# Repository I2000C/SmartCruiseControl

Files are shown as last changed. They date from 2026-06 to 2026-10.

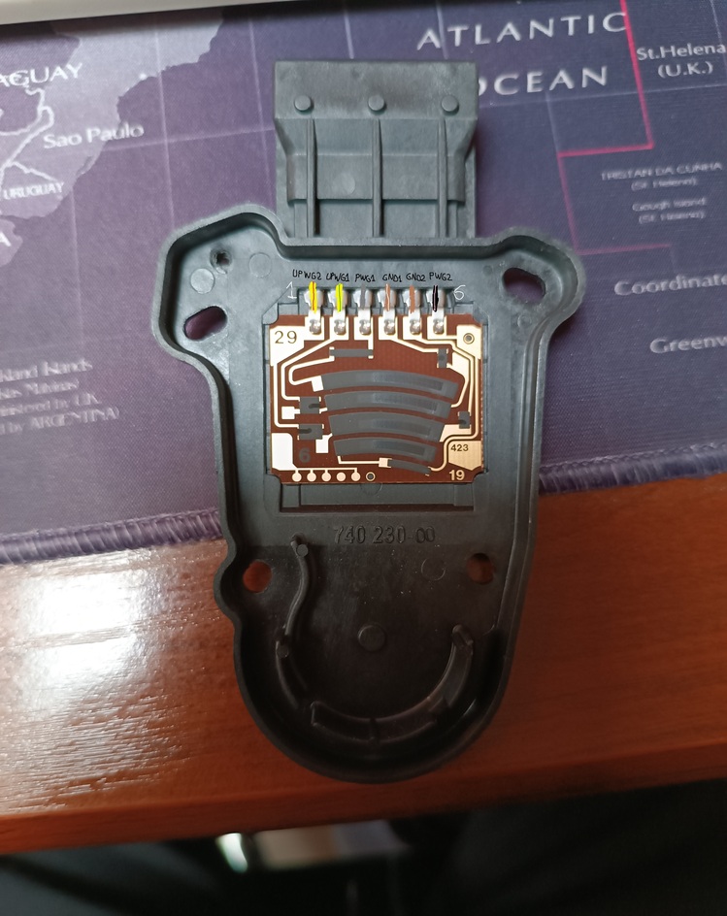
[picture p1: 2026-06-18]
doc/throttle/Throttle potentiometer pinout.jpg

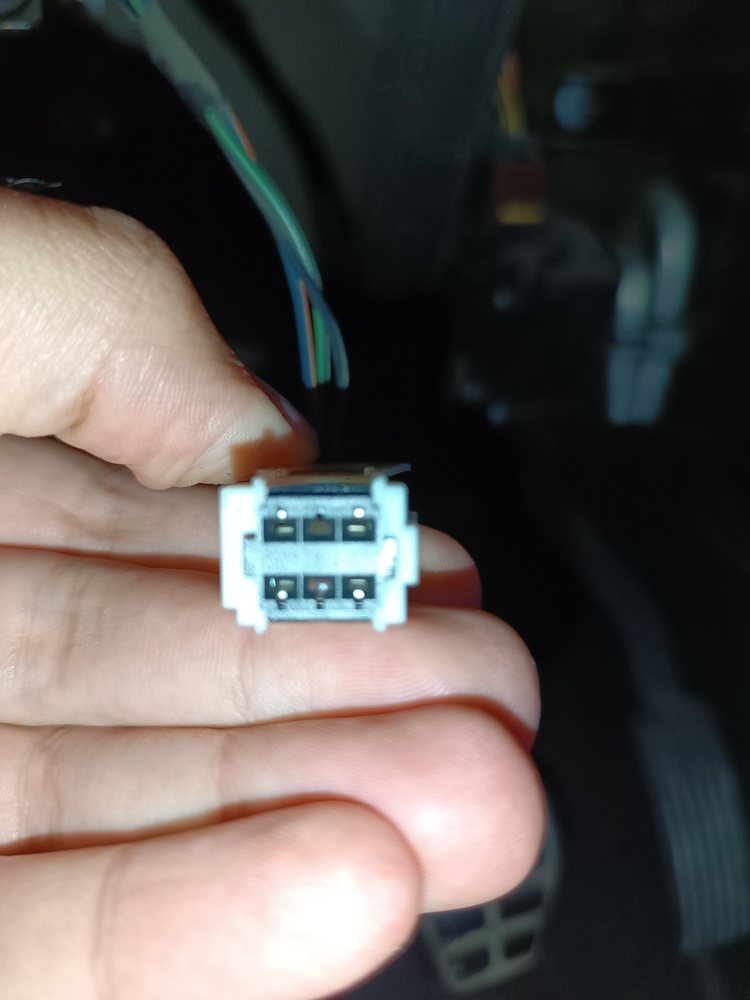
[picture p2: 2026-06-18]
doc/brake_clutch/brake switch connector 2.jpg

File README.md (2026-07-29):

# SmartCruiseControl

SmartCruiseControl is an embedded ESP32 project that implements cruise control using CAN Bus data, with vehicle state monitoring and ELM327 command emulation for the **Smart forfour 454** car

## Description

The software runs on an ESP32 using the Arduino framework and focuses on:

- Reading CAN Bus frames from a Smart vehicle.
- Estimating speed, RPM, distance, fuel level, and other critical vehicle parameters.
- Cruise control with PID, button-based enable/disable, and throttle override handling.
- Basic ELM327 emulation for OBD-II `01xx` and `22xx` command responses.
- Cruise control status indication using an LED.

## Key features

- CAN Bus listen-only mode (`TWAI_MODE_LISTEN_ONLY`) at 500 kbps.
- Support for reading the following key CAN IDs:
  - `0x09E` - total distance
  - `0x200` - speed
  - `0x208` - brake intensity and extra speed data
  - `0x210` - accelerator pedal position
  - `0x308` - engine RPM
  - `0x408` - fuel level
  - `0x416` - battery voltage
  - `0x423` - door status
  - `0x608` - refrigerant temperature and fuel rate
- Cruise control state machine with:
  - `STATE_OFF`
  - `STATE_ACTIVE`
  - `STATE_OVERRIDE`
- ELM327 interface over `Serial` with basic `AT`, `01`, and `22` command handling.

## Project structure

- `platformio.ini` - PlatformIO configuration for ESP32.
- `src/main.cpp` - main entry point and FreeRTOS task setup.
- `include/` - constants, state definitions, and shared headers.
- `lib/` - modular libraries:
  - `can/` - CAN bus reading and decoding.
  - `cruise_control/` - cruise control logic.
  - `elm327/` - ELM327 emulation and OBD response handling.
  - `fuel_range_estimator/` - fuel range estimation.
  - `indicator_led/` - PWM LED status indicator.
  - `pid_controller/` - generic PID controller.
  - `speed_estimator/` - speed estimation from CAN frames.
  - `throttle/` - throttle output and override management.
  - `buttons/` - analog button reading and cruise control button detection.
- `doc/` - CAN Bus reverse engineering documentation.
- `test/` - PlatformIO testing notes and setup.

## Requirements

See `requirements.md` file for required software and hardware

## How to build

See `how-to-build.md` file to build software and hardware

## Usage

- The system starts by creating FreeRTOS tasks for CAN reception, CAN processing, and ELM327 emulation.
- The indicator LED shows cruise control status:
  - off = cruise control disabled
  - full brightness = cruise control active
  - fading = throttle override active
- Cruise control buttons support `SET`, `RESUME`, and `CANCEL`.
- Pressing the accelerator while cruise control is active transitions the system to `STATE_OVERRIDE`.

## Notes

- The project is designed for the Smart Forfour 454 (2006) model, as described at the beginning of `doc/CAN bus reverse engineering.md`.
- With the necessary modifications, it could be adapted to other vehicles that use CAN Bus, electronic throttle, and physical brake/clutch switches.
- The implementation is based on CAN data documented in `doc/CAN bus reverse engineering.md`.
- The ESP32 pinout reference image is available at `doc/ESP32 pinout.png` and is used under Creative Commons BY-NC-ND via www.mischianti.org.

## Inspirations

This project was inspired by:

- [esp32_cruise_control](https://github.com/successdt/esp32_cruise_control)
- [autocruise](https://github.com/SantiagoDelEstero/autocruise)
- [esp32-elm327-cruise-control](https://github.com/ipepe-oss/esp32-elm327-cruise-control)

## License

See the `LICENSE` file for the project license terms.

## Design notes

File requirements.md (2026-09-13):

# Requirements

## Software

- VSCode (https://code.visualstudio.com/)
- PlatformIO extension installed on VSCode (https://platformio.org/install/ide?install=vscode).

## Hardware

- Wires
- Soldering iron (and related soldering stuff)
- A small switch (to safely disconnect power supply if something unexpected happens)
- Male USB to wires
- Female USB to wires
- SN65HVD230
- HK19F-DC 5v-SHG (other DPDT relays may work)
- IRLZ44N x1 (other MOSFETs may work)
- 1N4003 x1 (other flyback diodes may work)
- 2N3904 x4 (other NPN transistors may work)
- Capacitors and resistors. See BOM (Bill of Materials): [BOM](https://html-preview.github.io/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)
- ESP32 devkit v1 board

esp32 board

- Male OBDII connector to wires, including at least **GND**, **CAN low** and **CAN high**

obdII connector to wires

- Throttle connector (reference: XG7061C-1.5-11/21 1473284-1)

XG7061C automotive 6-hole connector

- JST-XH 2.54mm connector kit

JST-XH connector kit

- Steering wheel control button 7 key

steering wheel control button 7 key

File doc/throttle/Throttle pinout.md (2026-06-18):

# Throttle pinouts

## Pinouts
- **UPWG2** (yellow/red wire) = 2.38V (~= 2.5V)
- **UPWG1** (yellow/green wire) = 5V
- **PWG1** (gray wire) = APPS1
- **GND1** (brown/pink wire) = GND
- **GND2** (brown wire) = GND
- **PWG2** (black/pink wire) = APPS2

## Voltage range (measured with multimeter)
- **APPS1**: 0.9772V (0%) --> 3.174V (100%)
- **APPS2**: 0.4588V (0%) --> 1.4850V (100%)

## Relation between APPS 1 and APPS2
APPS1 / APPS2 ~= 2.13

NOTE: APPS means "Accelerator Pedal Position Sensor"

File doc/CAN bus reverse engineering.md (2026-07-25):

# Smart Forfour 454 (2006) CAN Bus Reverse Engineering (1.5 CDI Diesel)

This document describes observed CAN bus frames from a **Smart Forfour 454 (2006, 1.5 CDI diesel)**.  
Values are based on real-world sniffing and are partially reverse engineered.

It has been observed that some signals are similar between this vehicle and the **Smart Fortwo 451**, as documented in the following project:
https://hackaday.io/project/19931-smart-fortwo-can-bus-reverse-engineering

---

## 0x002 — Length: 2 bytes
- Byte 0: Oscillates between 0 and 1
- Byte 1: Counter from 0 to 0xFE (254)

---

## 0x038 — Length: 5 bytes
- Bytes 0–4: Always `0xFF`

---

## 0x09E (+) — Length: 7 bytes
- Bytes 0–2: Always `0xFF`
- Byte 3: Always `0xFE`
- Bytes 4–6: 24-bit value → **total distance traveled (in 0.1 km units)**

---

## 0x0C0 — Length: 5 bytes
- Bytes 0–1: Likely signed 16-bit value (unknown meaning)
- Byte 2: Possibly braking intensity?
- Byte 3: Always `0x07`
- Byte 4: Unknown counter-like value

---

## 0x101 (*) — Length: 8 bytes
Very unusual frame (only sent 5 times)

- Byte 0: 0 → 255 cycle
- Byte 1: 0xC5 → 0
- Byte 2: 0x65 → 0
- Byte 3: 0xEE → 0
- Byte 4: 0x38 → 0
- Byte 5: 0x89 → 0
- Byte 6: 0xB0 → 0
- Byte 7: 0x50 → 0

---

## 0x111 (*) — Length: 8 bytes
Sent only 4 times

- Byte 0: Always 0
- Byte 1: Always 0xAB
- Byte 2: Always 0x17
- Byte 3: Always 0x1A
- Bytes 4–7: Always 0

---

## 0x119 (*) — Length: 8 bytes
Sent only 9 times

- Bytes 0–1: Always 0
- Byte 2: 1 → 0 transition
- Bytes 3–4: Always 0
- Byte 5: Always 0x08
- Byte 6: Increases slowly from 1 to 9
- Byte 7: Varies (0x03 → 0xB8)

---

## 0x130 — Length: 8 bytes
- Byte 0: Oscillates between 0 and 11
- Byte 1: Fast counter (0 → 0xFE)
- Byte 2: Unknown
- Bytes 3–5: Oscillating values
- Byte 6: Usually 0 (rare peak at 0x08)
- Byte 7: Counter-like (0 → 0xFF)

---

## 0x194 (*) — Length: 1 byte
- Byte 0: Always `0xFE`

---

## 0x1A4 (*) — Length: 8 bytes
Constant frame

- Byte 0: 0x05
- Byte 1: 0x03
- Byte 2: 0x20
- Byte 3: 0x02
- Byte 4: 0x0B
- Byte 5: 0xC3
- Bytes 6–7: Always 0

---

## 0x1E1 — Length: 8 bytes
- Byte 0: 0x81 → 0 → stays 0
- Bytes 1–7: Always 0

---

## 0x200 — Length: 8 bytes
- Byte 0:
  - Bit 1: **Handbrake status**
- Byte 1: Counter (0 → 0x7D)
- Bytes 2–3: **Vehicle speed (km/h × 0.05)**
- Bytes 4–5: **Vehicle speed (km/h × 0.05)**
- Bytes 6–7: **Vehicle speed (km/h × 0.05)**

---

## 0x208 (+) — Length: 8 bytes
- Byte 0: Always 0
- Byte 1: 0x30 → 0x20 → stable
- Bytes 2–3: **Brake intensity (max value: 0x4230)**
- Bytes 4–5: **Vehicle speed (km/h × 0.05)**
- Bytes 6–7: **Vehicle speed (km/h × 0.05)**

---

## 0x210 (+) — Length: 8 bytes
- Bytes 0–1: Always 0
- Byte 2: **Accelerator pedal sensor 1 (0 → 0xA1)**
- Byte 3: Transient value, stabilizes at 0x40
- Bytes 4–7: Always 0

---

## 0x212 (+) — Length: 8 bytes
- Byte 0: 0 → 3
- Byte 1: 0 → 0x86 → 0x84
- Bytes 2–3: Always 0
- Bytes 4–5: **Accelerator pedal sensor 2 (0x277C → 0x2A0A)**
- Bytes 6–7: Always 0

---

## 0x270 (*) — Length: 8 bytes
- Bytes 0–1: Counters (0 → 0xFF)
- Bytes 2–7: Always 0xFF

---

## 0x2F1 — Length: 2 bytes
- Byte 0: Unknown
- Byte 1: 0x80 → 0

---

## 0x300 — Length: 8 bytes
- Byte 0: Always 0
- Byte 1: 0x08 → 0x8D
- Byte 2: Always 0x1F
- Byte 3: Always 0xFF
- Byte 4: 0 → 0x80 oscillation
- Byte 5: Always 0
- Bytes 6–7: Unknown 16-bit value

---

## 0x308 (+) — Length: 8 bytes
- Byte 0: 0 or 0x80 (state-dependent)
- Bytes 1–2: **Engine RPM (16-bit)**
- Byte 3: 0x0C → 0x00 decay
- Byte 4: 0x10 → spike → 0
- Byte 5: Unknown (0xFF → 0x82 stabilizing)
- Byte 6: Always 0x20
- Byte 7: Always 0

---

## 0x312 — Length: 8 bytes
All fields unknown (16-bit blocks)

---

## 0x328 — Length: 8 bytes
- Bytes 0–1: Always 0xFF
- Byte 2: Oscillates (0x3B → 0xB8)
- Byte 3: Always 0
- Byte 4: 0xDF → 0xC0 → 0xD0 → 0xC0
- Byte 5: Oscillates (0–0x47)
- Bytes 6–7: Counters (0 → 0xFF)

---

## 0x408 (+) — Length: 8 bytes
- Byte 0: **Fuel tank level (liters)**
- Byte 1: Always 0
- Byte 2: ~110 (0x6E)
- Byte 3: Always 0
- Byte 4: Always 0xFE
- Byte 5: Always 0xC3
- Byte 6: Always 0x4F
- Byte 7: Always 0

---

## 0x40C (+) — Length: 5 bytes
- Byte 0: Always 0xFF
- Byte 1: **Speed (dashboard km/h)**
- Byte 2: Always 0x80
- Byte 3: Always 0
- Byte 4: Always 0x40

---

## 0x412 — Length: 8 bytes
- Byte 0: Always 1
- Byte 1: **Speed (dashboard km/h + slightly offset)**
- Byte 2: Always 2
- Byte 3: 0xA0
- Byte 4: Slowly increasing unknown value
- Byte 5: Always 0
- Byte 6: Always 1
- Byte 7: 0xDF

---

## 0x416 (+) — Length: 8 bytes
- Byte 0: **Battery voltage (in 0.1V units)**
- Bytes 1–7: Always 0

---

## 0x423 (+) — Length: 6 bytes
- Byte 0:
  - Bits 0–1: **Ignition state (LOCK = 0b00 / ACC = 0b01 / ON = 0b11 / START = 0b10)**
  - Bit 2: **Position lights**
  - Bit 3: **Front fog lights**
  - Bit 4: **Rear fog light**
- Byte 1:
  - Bit 0: **Right turn signal**
  - Bit 1: **Left turn signal**
  - Bit 2: **High beam headlights**
  - Bit 3: **Reverse light**
- Byte 2:
  - Bit 0: **Right front door**
  - Bit 1: **Left front door**
  - Bit 3: **Right rear door**
  - Bit 4: **Left rear door**
  - Bit 6: **Trunk door**
- Byte 3:
  - Bit 0: **Fan state**
- Byte 4: Always 0x15
- Byte 5: 0x05–0x06

---

## 0x443 (*) — Length: 6 bytes
- Byte 0: 0 → 2 spike
- Byte 1: 0xFF → 0 → 0x23 cycle
- Bytes 2–5: Always 0

---

## 0x536 (*) — Length: 8 bytes
Constant diagnostic-like frame

- Byte 0: 0xAB
- Byte 1: 0x68
- Byte 2: 0x4C
- Byte 3: 0xB1
- Byte 4: 0x0C
- Byte 5: 0
- Byte 6: 0x02
- Byte 7: 0

---

## 0x608 (+) — Length: 8 bytes
- Byte 0: **Coolant temperature (°C + offset 40)**
- Byte 1: Always 0
- Byte 2: 0x18
- Byte 3: 0x66
- Byte 4: 0xFF
- Bytes 5–6: **Fuel consumption (L/h × 0.01)**
- Byte 7: Always 0

---

## 0x7C0 (*) — Length: 2 bytes
Single transmission frame

- Byte 0: 0x53
- Byte 1: 0xF5

---

## Notes
- Frames marked with `(*)` are rare or burst transmissions.
- Frames marked with `(+)` likely contain key vehicle state signals.
- Several signals are still unknown and require further reverse engineering.

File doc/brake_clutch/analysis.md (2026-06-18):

# Brake and Clutch Switch Analysis (Smart Forfour 454, 2006)

## System Overview

Both the brake and clutch pedals use simple switch assemblies that interface with the ECU through pull-up resistors. The ECU reads these signals as logic levels (approximately 0 V or ~12 V depending on pedal state), rather than clean digital GPIO-style signals.

Both switches behave similarly:

* **ECU input is pulled up internally to ~12 V**
* **Switch closure pulls the signal to GND**

# Brake Switch

## Pinout

The brake switch uses a 4-pin connector with the following wiring:

* Brown wire: **+12 V supply**
* Black wire: **GND**
* Green/black wire: **ECU signal**
* Blue/orange wire: **Brake lights output**

### Internal grouping

The switch contains two independent circuits:

* **Power to brake lights**

  * +12 V ↔ Brake lights
* **ECU sensing circuit**

  * GND ↔ ECU signal

## Physical location and identification

The brake switch is located at the pedal assembly and its connector and wiring can be identified in the following images:

* `brake switch connector.jpg`
* `brake switch connector2.jpg`
* `brake switch connector3.jpg`

These images show the physical connector, pin arrangement, and wiring colors used for identification.

## Electrical behavior

### Brake NOT pressed (idle state)

* GND is connected to ECU pin
* ECU sees approximately **0 V**
* Brake lights circuit is open

### Brake PRESSED

* +12 V is connected to brake lights output
* ECU input is disconnected from GND and pulled up internally
* ECU sees approximately **11–12 V**

Measured behavior:

* Idle: ~0 V at ECU pin
* Active: ~11–12 V at ECU pin

## ECU pull-up resistor estimation

Measurements using an external 100 kΩ resistor allowed estimation of the internal pull-up:

* Without external load: ~11.22 V
* With 100 kΩ load: ~10.98 V

Estimated internal pull-up resistance:

* **≈ 2.2 kΩ**

## Signal conditioning for microcontroller (ESP32)

Since the ECU signal operates at automotive voltage levels (~12 V), direct connection to an ESP32 GPIO is not safe.

### Recommended approach: NPN transistor interface

A simple level-shifting circuit can be used using a **2N3904 NPN transistor**.

**Connections:**

* Base (B): ECU signal via **10 kΩ resistor**
* Collector (C): ESP32 GPIO input (with pull-up enabled)
* Emitter (E): GND

This inverts the signal:

* Brake NOT pressed → GPIO HIGH
* Brake pressed → GPIO LOW

# Clutch Switch

## Pinout

The clutch switch is electrically similar to the brake ECU sensing circuit but simpler:

* Black wire: **GND**
* Red/yellow wire: **ECU signal**

Only two wires are present because this switch does not control any secondary load like brake lights.

## Physical location and identification

The clutch switch is located behind the fuse box and is not directly visible. Access is limited, so the correct wire was identified by probing, testing, and carefully pulling and tracing the harness until the correct signal line was found.

The identified clutch signal wire is shown in:

* `clutch switch wire.jpg`
* `clutch switch wire2.jpg`

## Electrical behavior

### Clutch NOT pressed (idle state)

* ECU signal is pulled up internally
* Measured voltage: **~11.7 V**

### Clutch PRESSED

* Signal is pulled to ground
* Measured voltage: **~0 V**

Measured with external 100 kΩ reference resistor:

* With load: ~11.4 V
* Without load: ~11.7 V

## ECU pull-up resistor estimation

Estimated internal pull-up:

* **≈ 2.6 kΩ**

This is consistent with the brake circuit and indicates a similar ECU input design.

## Signal conditioning for ESP32

The same NPN transistor approach applies:

* Base: ECU signal via 10 kΩ resistor
* Collector: ESP32 GPIO (pull-up enabled)
* Emitter: GND

Logic is inverted:

* Clutch released → HIGH
* Clutch pressed → LOW

# Notes

* Both pedal inputs are **12 V automotive logic signals**, not direct digital inputs.
* Internal ECU pull-ups are relatively low (~2–3 kΩ), indicating relatively strong signal driving capability.
* Using a transistor interface is strongly recommended for reliability and protection of microcontroller inputs.
* Measurement consistency suggests both brake and clutch inputs share a similar ECU input architecture, despite slight differences in pull-up values.

# Circuit visualization

The electrical circuit of the brake pedal switch (the clutch switch is not shown due to its very similar behavior) can be visualized using the Falstad Circuit Simulator:

* Go to: https://www.falstad.com/circuit/circuitjs.html
* Load the file: `brake-pedal-switch-circuit.txt`

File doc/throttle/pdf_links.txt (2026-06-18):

These 2 pdf files have been downloaded from:
https://es.scribd.com/document/216611532/Smart-Forfour-454-Wiring-Diagram
https://es.scribd.com/document/577662516/Smart-FORFOUR-2006-Wiring-Diagram-of-Engine-Electronics-Electronic-Accelerator-Transmission-MEG-With-Clutch-Sheet-2
https://es.scribd.com/document/444638970/Sensor-del-pedal-del-acelerador

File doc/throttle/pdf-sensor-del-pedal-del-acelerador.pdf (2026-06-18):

## Somsir hol pohel hol ecolorehir

### Códi cimocter ol isckliscipki pere roelkzer ume pruo`e7-Somsir ho piskckóm hol ecolorehir

Cimocto ol tordkmel ho cidpri`eckóm @MC om ol cemel E hol ^kciScipo. Ciliquo ume `rkhe ho cicihrkli mofre om le simhe mofre (mofetkvi) y cimocto oste e um pumti ho tide
ho tkorre ehocuehi. Cimocto ume simhe ho ecupumture el tordkmel rigi (pisktkvi) pere roelkzer ume ho les cimoxkimos hol pitomckódotri homtri ho le tide d÷ltkplo hol somsir ho piskckóm hol pohel hol ecolorehir, tel y cidi so duostre om le tre om le Jkfure ?0.5.

Cimocto ol tordkmel ho cidpri`eckóm @MC om ol cemel @ hol ^kciScipo. Cimocto ume
simhe ho ecupumture el tordkmel rigi (pisktkvi) pere roelkzer le itre cimoxkóm el pitomckódotri homtri ho le tide d÷ltkplo hol somsir hol pohel hol ecolorehir r hol pohel hol ecolorehir. Sk bey . Sk bey
tordkmel ho eutidickóm hkspimk`lo, puoho utklkzerso om lufer hol dëtihi ho "`eca-pkmmkmf".

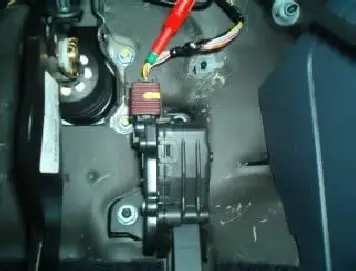
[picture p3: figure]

Jkf. ?0.5
Ogodpli ho jirde ho imhe hol Ogodpli ho jirde ho imhe hol somsir ho piskckóm hol somsir ho piskckóm hol

### pohel hol ecolorehir

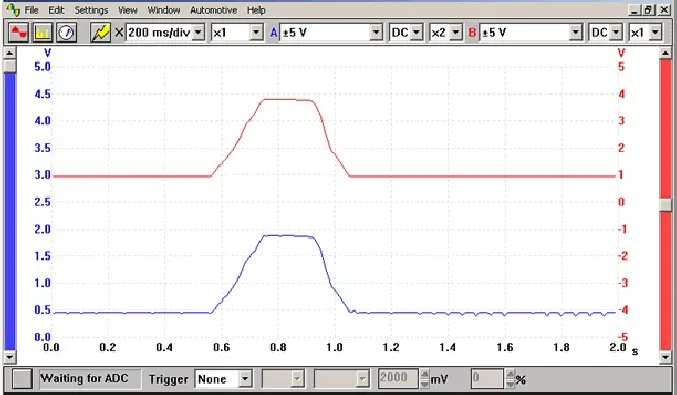
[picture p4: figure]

Mites si`ro le jirde ho imhe ho Mites si`ro le jirde ho imhe ho cimtril hol ecoloreh cimtril hol ecolorehir

### oloctrómkci

Om osto ogodpli, ol somsir ho piskckóm hol pohel hol ecolorehir (E^^) os ho tkpi pitomckódotri. Pock`o his tomskimos ho rojoromck pitomckódotri. Pock`o his tomskimos ho rojoromcke hosho ol dóhuli ho cimtril hol trom ho hosho ol dóhuli ho cimtril hol trom ho pitomcke (^CD), cim his ce`los ho tide ho tkorre pitomcke (^CD), cim his ce`los ho tide ho tkorre y his ce`los ho soõel quo omväem ume his ce`los ho soõel quo omväem ume tomskóm verke`lo ho rofrosi el ^CD om roleckóm cim le piskckóm hol pohel hol ecolorehir. Le tomskóm ho le soõel omvkehe el ^CD puoho verker ho um je`rkcemto e itri, pori pri`e`lodomto mumce sorå suporkir e ? pri`e`lodomto mumce sorå suporkir e ? viltkis. viltkis.

### Kmjirdeckóm tëcmkce - Cimtril hol ecolorehir oloctrómkci

El eudomter ol mkvol hol cimtril oloctrómkci y le cimskfukomto rohucckóm om ol m÷dori ho pkozes docåmkces dóvklos, os kmovkte`lo quo voedis dås olodomtis cimtrilehis dohkemto olodomtis cimtrilehis dohkemto ce`lo.

_m ogodpli ho osti os ol cimtril hol ecolorehir. Le deyir perto ho lis vobäculis je`rkcehis om le ectuelkheh mi utklkzem um ce`lo pere ol ecolorehir, skmi um E^^ om cid`kmeckóm cim um ectuehir ho cimtril hol ecolorehir oloctrómkci (OXC), kmcirpiremhi um ditir ho ecolorehir oloctrómkci y um somsir ho piskckóm hol ecolorehir (X^S).

Ol E^^ suolo sor umi, i dås cid÷mdomto, his pitomckódotris eciplehis el pohel hol ecolorehir. Cuemhi so pkse ol ecolorehir, ume soõel ho tomskóm so omväe el ^CD

cidumkcemhi le piskckóm ectuel hol dksdi y pir li temti le oxkfomcke jäskce hol cimhuctir. Cidi rosultehi ho oste omtrehe, ol ^CD fomore ume selkhe el ectuehir cirrospimhkomto, om osto cesi ol OXC. Cidi so be domckimehi emtorkirdomto, ol E^^ suolo tomor his pitomckódotris. Ëstis so utklkzem cidi pruo`e ho pleusk`klheh y ted`këm pere esofurer um k`klheh y ted`këm pere esofurer um mkvol ho jumckimedkomti e pruo`e ho jellis.

So utklkzem verkis dëtihis pere fomorer le soõel. Le frem deyiräe utklkze le rojoromcke cid÷m ho ? viltkis, quo so odploe om ol skstode ho fostkóm hol ditir. Lis his dëtihis dås cidumos ho fomoreckóm ho soõelos sim lis skfukomtos7

### 5. Ol pitomckódotri 5 fomore ume soõel ho omtro >,3 y 8,2 viltkis (pkste rige om le

jkfure ?0.0) y ol pitomckódotri 0 fomore ume soõel ho omtro >,? y 8,2 viltkis (pkste ezul om le jkfure ?0.0). Cim ume piskckóm hol pohel hol ecolorehir e 8? frehis, ol pitomckódotri 5 puoho odktkr ume soõel ho 0 viltkis y ol pitomckódotri 0 ume s s y ol pitomckódotri 0 ume soõel ho 3 viltkis, e dihi ho ogodpli.

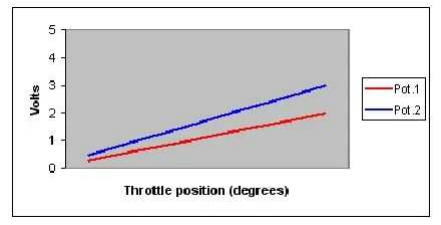
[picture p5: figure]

Jkfure ?0.0

### 0. Ol pitomckódotri 5 fomore ume soõel ho omtro >,3 y 8,2 viltkis (pkste rige om le

jkfure ?0.3) y ol pitomckódotri 0 fomore ume soõel ho omtro 8,2 y >,3 viltkis (pkste ezul om le jkfure ?0.3). Cim ume piskckóm hol pohel hol ecolorehir e > frehis, ol pitomckódotri 5 puoho odktkr ume soõel ho >,? viltkis y ol pitomckódotri 0 ume y ol pitomckódotri 0 ume soõel ho 8,? viltkis.

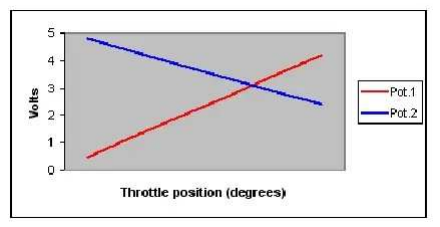
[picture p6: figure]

Jkfure ?0.3

Xres le rocopckóm ho les soõelos ho osto dihi, ol ^CD os cepez ho esofurer quo le kmjirdeckóm os cirrocte1 pir ogodpli, sk ol åmfuli E^^ os ho 8? frehis, ol pitomckódotri 5 odkto 0 viltkis y ol pitomckódotri 0 odkto 3 viltkis. Sk so prihuco elfume hosvkeckóm rospocti e ostis veliros, ol ^CD hotocte um pisk`lo jelli y rofkstre ol cóhkfi ho evoräe cirrospimhkomto. Sk ume pkste ho um pitomckódotri ceo, ol ^CD sorå cepez ho hotocter osti ted`këm y jumckimer om dihi e pruo`e ho jellis i ho odorfomcke, e domuhi olovemhi ol relomtä y lkdktemhi ol jumckimedkomti hol ecolorehir, kludkmemhi ted`këm le luz kmhkcehire ho evoräes (DKL). Ol usi ho lis his pitomckódotri ted`këm pordkto el ^CD cimtriler le volickheh e le quo so pkse ol ecolorehir y so ckorre le piskckóm hol ecolorehir, cimtrilemhi
esä le omtrehe ho cid`ustk`lo.

Jirdes ho imhe emirdelos - rosiluckóm ho Jirdes ho imhe emirdelos - rosiluckóm ho pri`lodes pri`lodes

Sk croo quo puoho be`or um pri`lode cim le soõel, cidpruo`o ol ce`loehi hosho ol ^CD el E^^.

Esof÷roso ho quo ol ^CD tkomo ume elkdomteckóm ehocuehe y ho quo so cimocte e tkorre cuemhi so roqukoro.

Cidpruo`o ol E^^ (hoscimoctehi) cim um ibdädotri.

### Hetis ho pkm

Ogodpli ho hetis ho pkm

Cidpri`ehi om um cidpimomto Sdert Jirjiur 5.5 ho fesilkme 0>>? D[. Bolle
cimoctir ho : pkms

Jkfure ?0.8

^km 54 0,? Z ho tomskóm ho rojoromcke (ederklli/rigi)
^km 04 ?,> Z ho tomskóm ho rojoromcke (ederklli/vorho)
^km 34 tomskóm ho soõel, eprix. 5 Z cim ol ecolorehir correhi y 3,2 Z cim ol ecolorehir e`korti (frks)
^km 84 > Z tide ho tkorre (derróm/`lemci)
^km ?4 > Z tide ho tkorre (derróm)

^km :4 Xomskóm ho soõel, eprix. >,? Z ecolorehir correhi y 5,2 Z ecolorehir e`korti (rise/mofri)

Xihes les ckjres kmhkcehes sim eprixkdehes y i`tomkhes dohkemto "`eca-pkmmkmf" cim ol omcomhkhi ectkvehi y le tide d÷ltkplo cimoctehe.

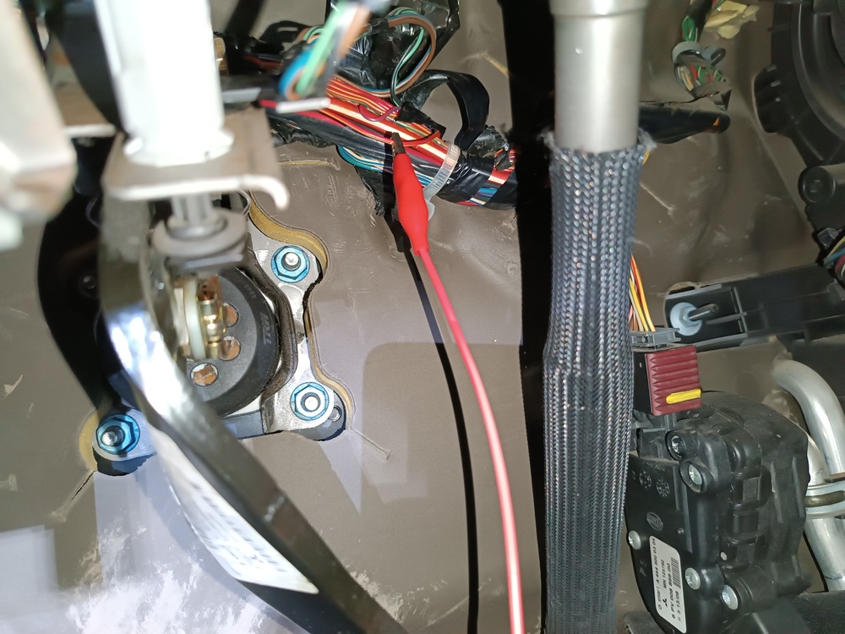
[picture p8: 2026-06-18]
doc/brake_clutch/clutch switch wire.jpg

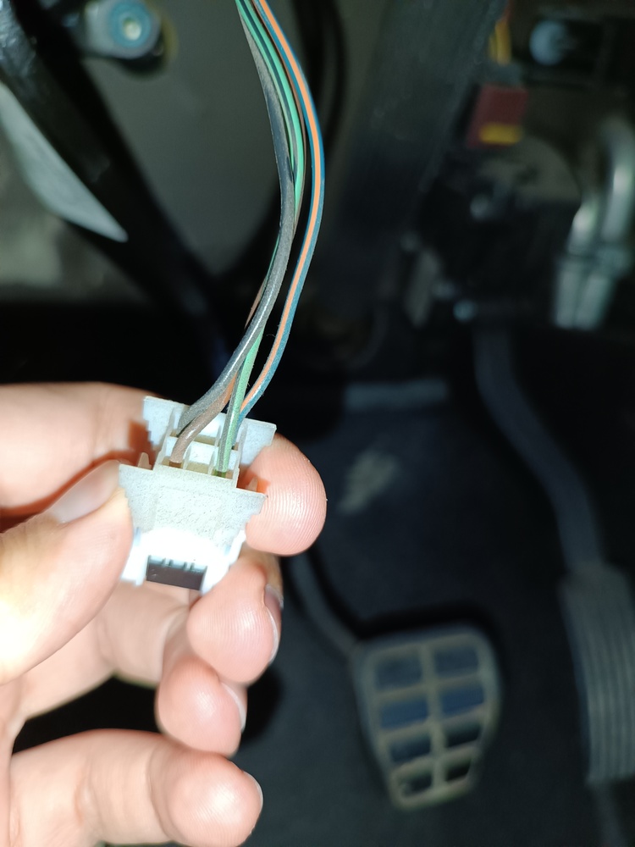
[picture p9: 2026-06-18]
doc/brake_clutch/brake switch connector.jpg

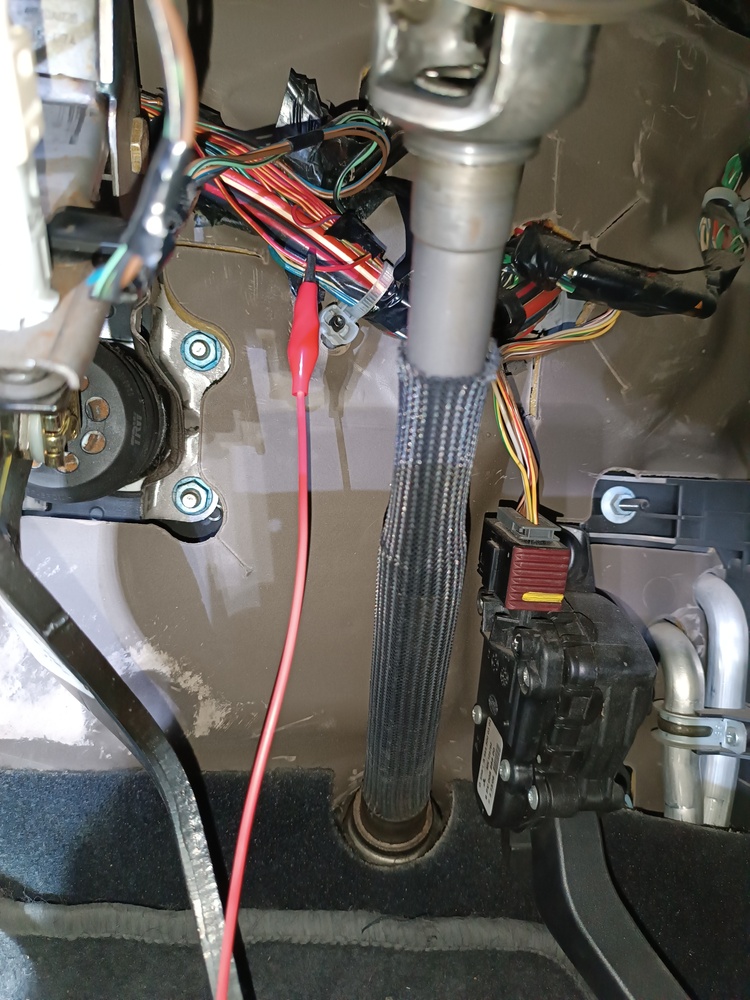
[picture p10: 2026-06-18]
doc/brake_clutch/clutch switch wire 2.jpg

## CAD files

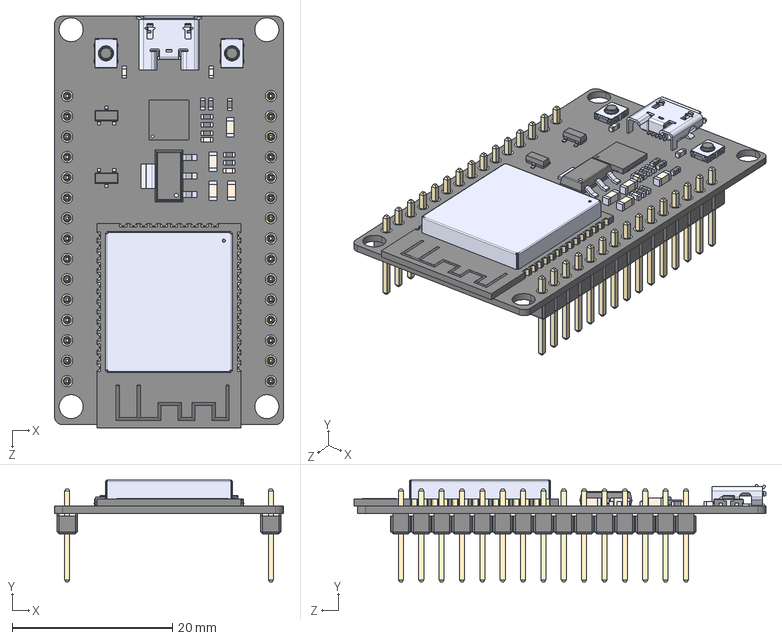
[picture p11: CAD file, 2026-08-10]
kicad_project/SmartCruiseControl/ESP32-3D-model/DEVKIT_V1_ESP32-WROOM-32.step
28.6 x 12.7 x 51.4 mm

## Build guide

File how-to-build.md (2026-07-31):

# How to build

## 1. VSCode and PlatformIO installation

You have to download and intall VSCode (https://code.visualstudio.com/) and then install the PlatformIO extension

## 2. Button key calibration

Once you have both VSCode and PlatformIO, you'll need to calibrate button keys because the values could differ from the ones present in the code.

To do that, create a new project in PlatformIO for the ESP32 board.

Then follow these steps:
1. Paste the next code in the `platformio.ini` file

```ini
[env:esp32dev]
platform = espressif32
board = esp32dev
framework = arduino
monitor_speed = 115200
upload_speed = 921600
```

2. Paste the next code in the `main.cpp` file:

```cpp
#include <Arduino.h>
#include <cinttypes>

#define LED_PIN GPIO_NUM_2
#define BUTTONS_PIN GPIO_NUM_35

uint16_t minValue = 0xFFFF;
uint16_t maxValue = 0;
uint32_t sumValue = 0;
uint16_t numSamples = 0;

void resetValues() {
    minValue = 0xFFFF;
    maxValue = 0;
    sumValue = 0;
    numSamples = 0;
}

inline uint16_t readFiltered(gpio_num_t pin, uint8_t samples = 16, uint8_t samplesToDiscard = 2) {
    uint16_t adcSamples[samples];

    if(samplesToDiscard * 2 >= samples) {
        samplesToDiscard = 0;
    }

    // Adquire ADC samples
    for(int i=0; i<samples; i++) {
        adcSamples[i] = analogRead(pin);
    }

    // Sort samples using insertion sort
    for(int index=1; index<samples; index++) {
        uint16_t currentSample = adcSamples[index];
        int8_t prevIndex = index - 1;

        while(prevIndex >= 0 && adcSamples[prevIndex] > currentSample) {
            adcSamples[prevIndex + 1] = adcSamples[prevIndex];
            prevIndex--;
        }

        adcSamples[prevIndex + 1] = currentSample;
    }

    // Compute the average after discarding extreme values
    uint32_t sum = 0;
    for(uint8_t i=samplesToDiscard; i<samples-samplesToDiscard; i++) {
        sum += adcSamples[i];
    }

    uint8_t validSamples = samples - (2 * samplesToDiscard);
    return sum / validSamples;
}

void detectButton(uint16_t rawSensorValue) {
    const char* buttonName = "";
    bool showRawValue = true;
    if(rawSensorValue <= 50) {
        buttonName = "Reject call";
        digitalWrite(LED_PIN, HIGH);
    } else if(rawSensorValue <= 250) {
        buttonName = "Mute";
        digitalWrite(LED_PIN, HIGH);
    } else if(rawSensorValue <= 800) {
        buttonName = "Answer call";
        digitalWrite(LED_PIN, HIGH);
    } else if(rawSensorValue <= 1600) {
        buttonName = "Next track";
        digitalWrite(LED_PIN, HIGH);
    } else if(rawSensorValue <= 1900) {
        buttonName = "Previous track";
        digitalWrite(LED_PIN, HIGH);
    } else if(rawSensorValue <= 2300) {
        buttonName = "Volume down";
        digitalWrite(LED_PIN, HIGH);
    } else if(rawSensorValue <= 2700) {
        buttonName = "Volume up";
        digitalWrite(LED_PIN, HIGH);
    } else {
        buttonName = "None";
        showRawValue = false;
        resetValues();
        digitalWrite(LED_PIN, LOW);
    }

    if(showRawValue) {
        numSamples++;
        sumValue += rawSensorValue;

        if(rawSensorValue < minValue) {
            minValue = rawSensorValue;
        }
        if(rawSensorValue > maxValue) {
            maxValue = rawSensorValue;
        }

        uint16_t averageValue = sumValue / numSamples;
        Serial.printf("Raw value: %4d (min: %4d, max: %4d, avg: %4d). Detected button name: %s\n", rawSensorValue, minValue, maxValue, averageValue, buttonName);
    }
}

void setup() {
    pinMode(LED_PIN, OUTPUT);
    Serial.begin(115200);
}

void loop() {
    uint16_t rawValue = readFiltered(BUTTONS_PIN);
    detectButton(rawValue);
    delay(100);
}
```

3. Flash the code to the ESP32 using the **Upload button** while the ESP32 is connected to the computer (Don't forget to press the BOOT button until flashing starts)
4. Connect the **GND wire** of the button set to **GND**
5. Connect the **KEY wire** of the button set to **GPIO 35**
6. Connect a **5k resistor** between **GPIO 35** and **3.3V**
7. Open the serial monitor in the computer while you press each button and check if read value is in the correct range and detected button is correct
8. If one or more buttons don't match, **you'll have to modify** the buttons module of the project

## 3.Downloading and flashing the project

To download the project, go to a folder, open a terminal and type `git clone https://github.com/I2000C/SmartCruiseControl.git --recurse-submodules`

Then open project folder in VSCode and flash it to the ESP32 using the **Upload button** while the ESP32 is connected to the computer (Don't forget to press the BOOT button until flashing starts)

## 4. Final steps

Before ordering the final board, I recomend that you test the project using one or more breadboards.

Once you get the project working, you can order the final board by generating the required gerber files from the kicad project (you'll need to install Kicad to do this) and then send these files to your favourite board supplier (e.g.: PCBWay, JLCPCB, ...)

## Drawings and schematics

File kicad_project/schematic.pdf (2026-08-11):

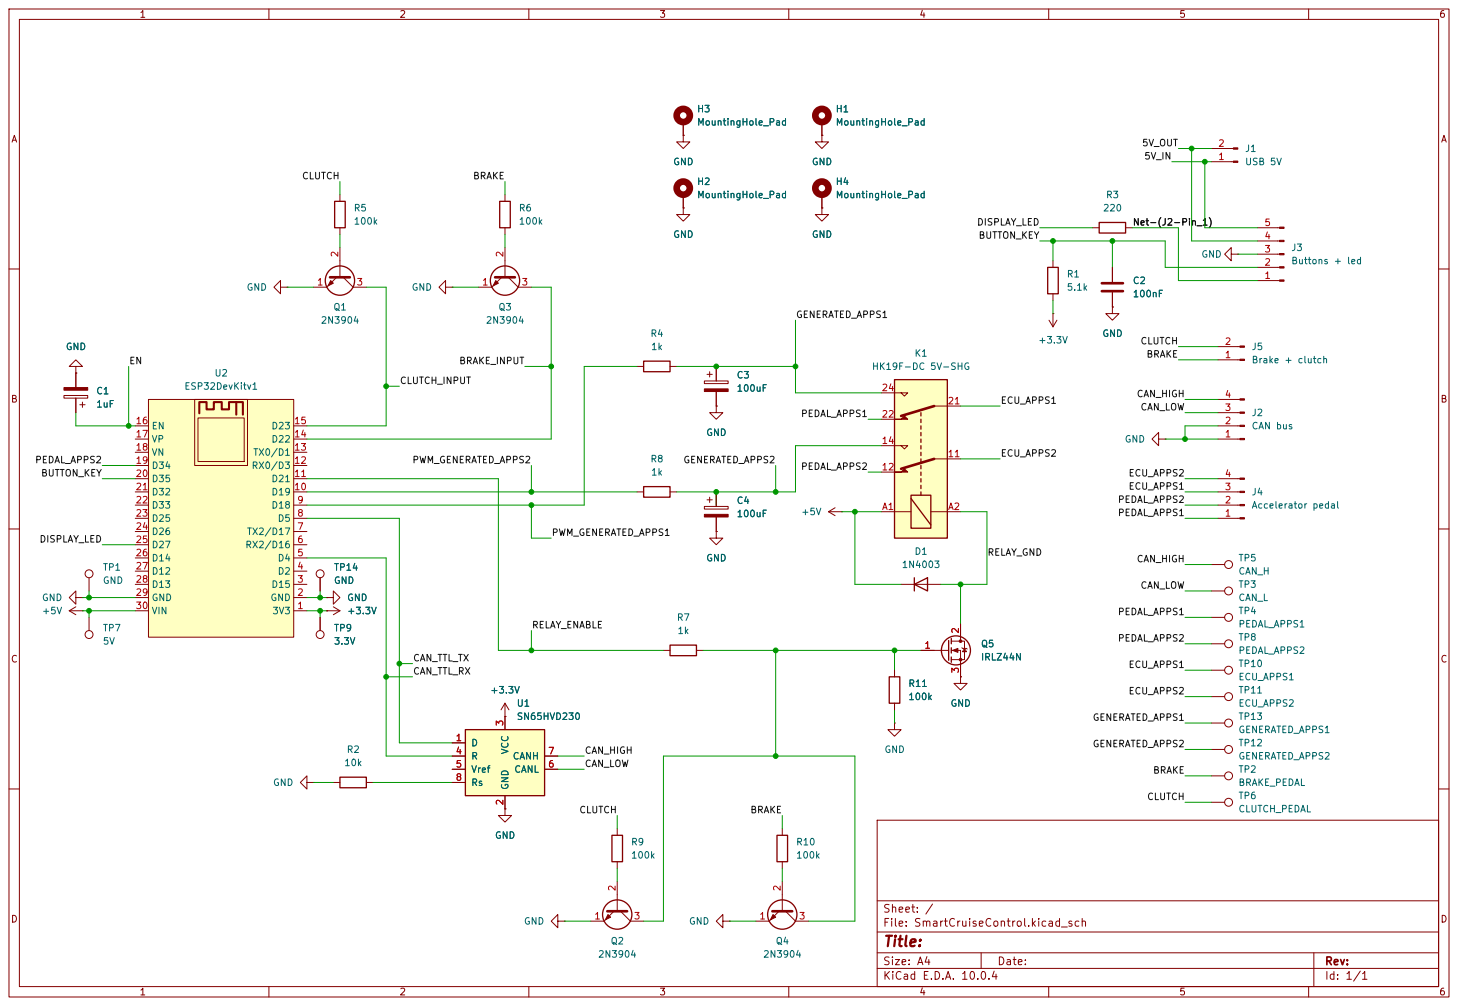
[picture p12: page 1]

Size: A4 | Rev:
KiCad E.D.A. 10.0.4 | Id: 1/1

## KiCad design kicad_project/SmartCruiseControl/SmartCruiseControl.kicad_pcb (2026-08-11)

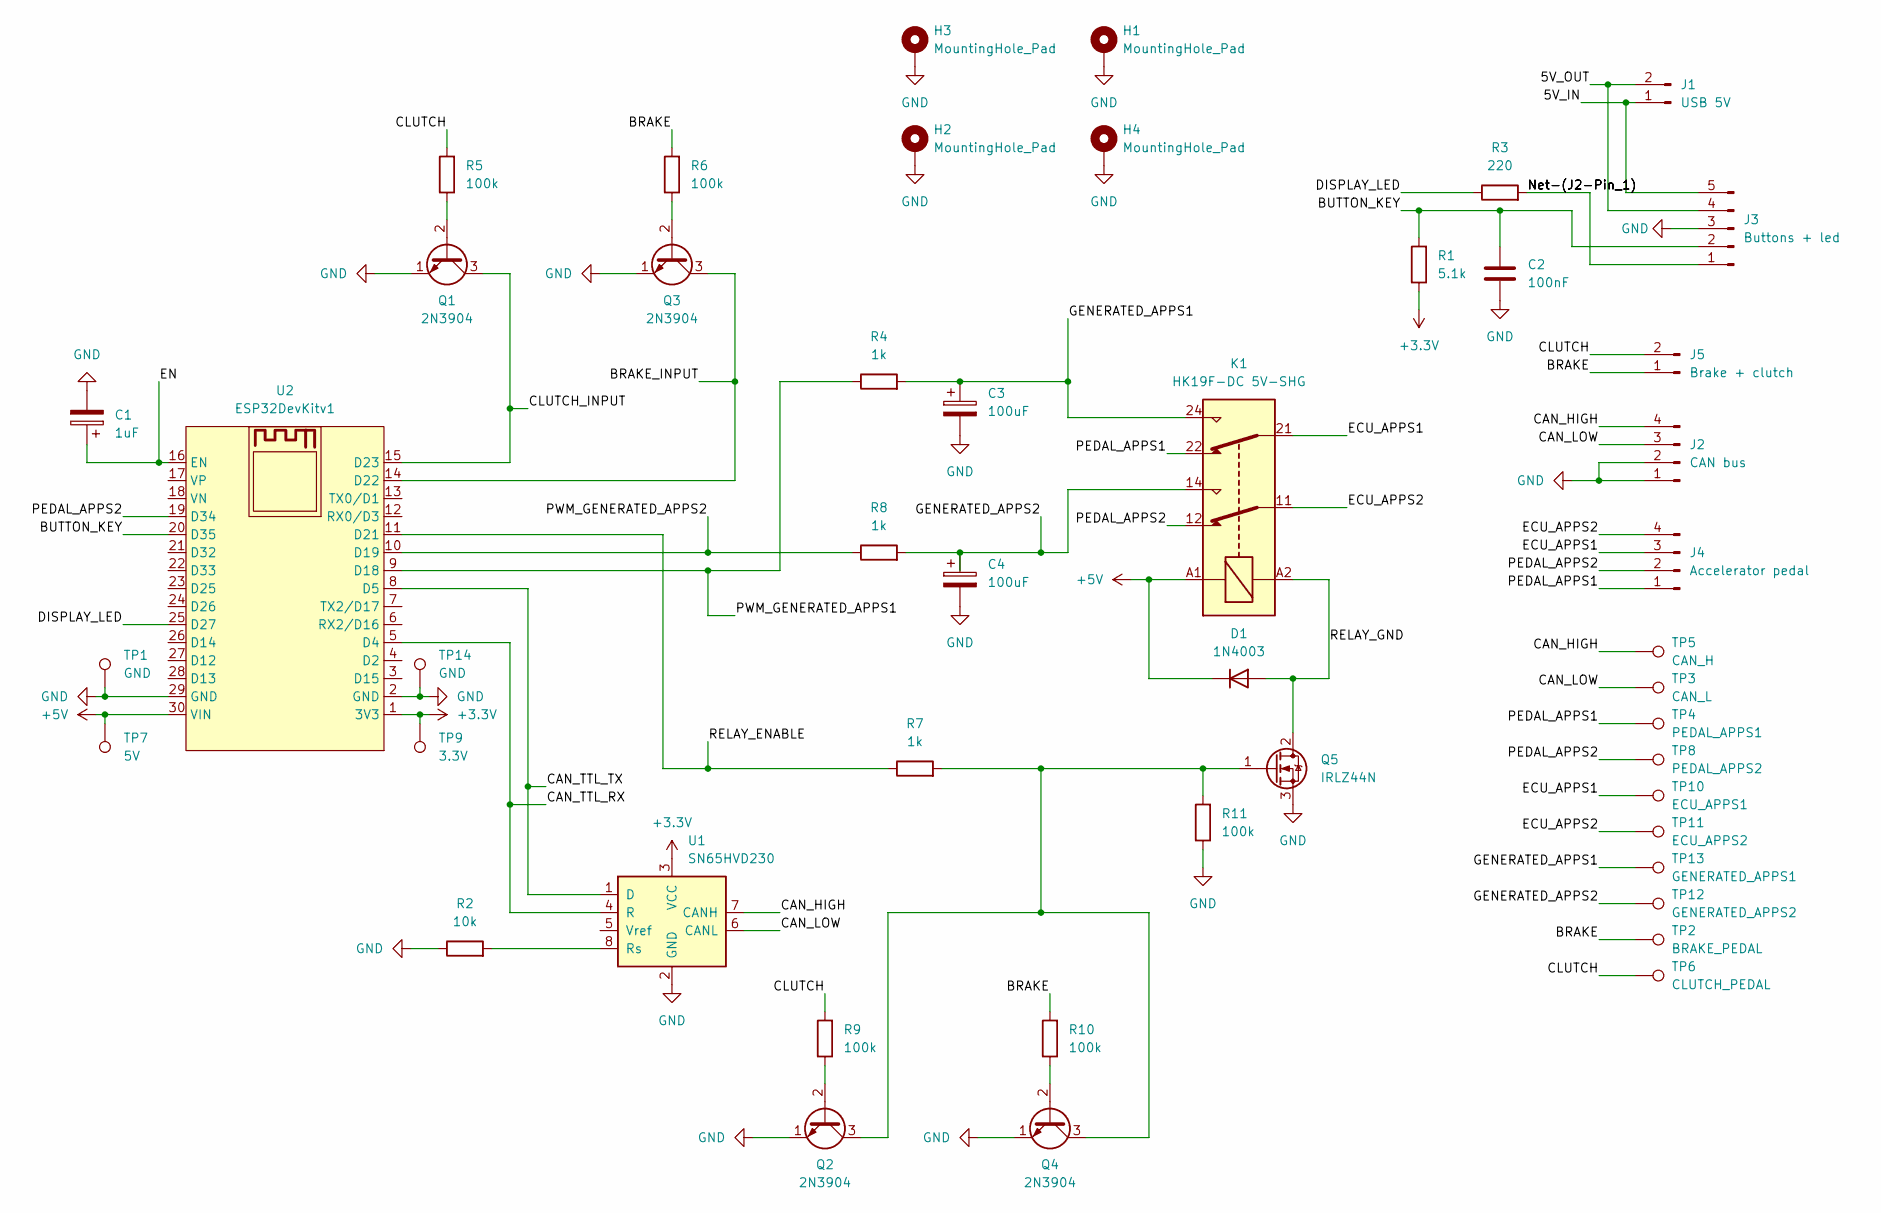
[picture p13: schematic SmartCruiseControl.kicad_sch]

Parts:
C1: 1uF; CP_Radial_D5.0mm_P2.00mm
C2: 100nF; C_Disc_D5.0mm_W2.5mm_P5.00mm
C3, C4: 100uF; CP_Radial_D5.0mm_P2.00mm
D1: 1N4003; D_DO-41_SOD81_P10.16mm_Horizontal
H1, H2, H3, H4: MountingHole_Pad; MountingHole_3.2mm_M3_Pad_Via
J1: USB 5V; JST_XH_B2B-XH-A_1x02_P2.50mm_Vertical
J2: CAN bus; JST_XH_B4B-XH-A_1x04_P2.50mm_Vertical
J3: Buttons + led; JST_XH_B5B-XH-A_1x05_P2.50mm_Vertical
J4: Accelerator pedal; JST_XH_B4B-XH-A_1x04_P2.50mm_Vertical
J5: Brake + clutch; JST_XH_B2B-XH-A_1x02_P2.50mm_Vertical
K1: HK19F-DC 5V-SHG; Relay_DPDT_Omron_G6A
Q1, Q2, Q3, Q4: 2N3904; TO-92_Inline
Q5: IRLZ44N; TO-220-3_Vertical
R1: 5.1k; R_Axial_DIN0207_L6.3mm_D2.5mm_P10.16mm_Horizontal
R2: 10k; R_Axial_DIN0207_L6.3mm_D2.5mm_P10.16mm_Horizontal
R3: 220; R_Axial_DIN0207_L6.3mm_D2.5mm_P10.16mm_Horizontal
R4, R7, R8: 1k; R_Axial_DIN0207_L6.3mm_D2.5mm_P10.16mm_Horizontal
R5, R6, R9, R10, R11: 100k; R_Axial_DIN0207_L6.3mm_D2.5mm_P10.16mm_Horizontal
TP1, TP14: GND; TestPoint_THTPad_2.0x2.0mm_Drill1.0mm
TP2: BRAKE_PEDAL; TestPoint_THTPad_D1.0mm_Drill0.5mm
TP3: CAN_L; TestPoint_THTPad_D1.0mm_Drill0.5mm
TP4: PEDAL_APPS1; TestPoint_THTPad_D1.0mm_Drill0.5mm
TP5: CAN_H; TestPoint_THTPad_D1.0mm_Drill0.5mm
TP6: CLUTCH_PEDAL; TestPoint_THTPad_D1.0mm_Drill0.5mm
TP7: 5V; TestPoint_THTPad_D2.0mm_Drill1.0mm
TP8: PEDAL_APPS2; TestPoint_THTPad_D1.0mm_Drill0.5mm
TP9: 3.3V; TestPoint_THTPad_D1.5mm_Drill0.7mm
TP10: ECU_APPS1; TestPoint_THTPad_D1.0mm_Drill0.5mm
TP11: ECU_APPS2; TestPoint_THTPad_D1.0mm_Drill0.5mm
TP12: GENERATED_APPS2; TestPoint_THTPad_D1.0mm_Drill0.5mm
TP13: GENERATED_APPS1; TestPoint_THTPad_D1.0mm_Drill0.5mm
U1: SN65HVD230; SOIC-8_3.9x4.9mm_P1.27mm
U2: ESP32DevKitv1

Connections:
+3.3V: R1.1, TP9.1 (1_1), U1.3 (VCC), U2.1 (3V3)
+5V: D1.1 (K), K1.A1, TP7.1 (1_1), U2.30 (VIN)
/5V_IN: J1.1, J3.5
/5V_OUT: J1.2, J3.4
/BRAKE: J5.1, R6.2, R10.2, TP2.1 (1_1)
/BRAKE_INPUT: Q3.3 (C), U2.14 (D22)
/BUTTON_KEY: C2.1, J3.2, R1.2, U2.20 (D35)
/CAN_HIGH: J2.4, TP5.1 (1_1), U1.7 (CANH)
/CAN_LOW: J2.3, TP3.1 (1_1), U1.6 (CANL)
/CAN_TTL_RX: U1.4 (R), U2.5 (D4)
/CAN_TTL_TX: U1.1 (D), U2.8 (D5)
/CLUTCH: J5.2, R5.2, R9.2, TP6.1 (1_1)
/CLUTCH_INPUT: Q1.3 (C), U2.15 (D23)
/DISPLAY_LED: R3.1, U2.25 (D27)
/ECU_APPS1: J4.3, K1.21, TP10.1 (1_1)
/ECU_APPS2: J4.4, K1.11, TP11.1 (1_1)
/EN: C1.1, U2.16 (EN)
/GENERATED_APPS1: C3.1, K1.24, R4.2, TP13.1 (1_1)
/GENERATED_APPS2: C4.1, K1.14, R8.2, TP12.1 (1_1)
/Net-(J2-Pin_1): J3.1, R3.2
/PEDAL_APPS1: J4.1, K1.22, TP4.1 (1_1)
/PEDAL_APPS2: J4.2, K1.12, TP8.1 (1_1), U2.19 (D34)
/PWM_GENERATED_APPS1: R4.1, U2.9 (D18)
/PWM_GENERATED_APPS2: R8.1, U2.10 (D19)
/RELAY_ENABLE: R7.1, U2.11 (D21)
/RELAY_GND: D1.2 (A), K1.A2, Q5.2 (D)
GND: C1.2, C2.2, C3.2, C4.2, H1.1 (1_1), H2.1 (1_1), H3.1 (1_1), H4.1 (1_1), J2.1, J2.2, J3.3, Q1.1 (E), Q2.1 (E), Q3.1 (E), Q4.1 (E), Q5.3 (S), R2.1, R11.1, TP1.1 (1_1), TP14.1 (1_1), U1.2 (GND), U2.2 (GND), U2.29 (GND)
unnamed: Q1.2 (B), R5.1
unnamed: Q2.2 (B), R9.1
unnamed: Q2.3 (C), Q4.3 (C), Q5.1 (G), R7.2, R11.2
unnamed: Q3.2 (B), R6.1
unnamed: Q4.2 (B), R10.1
unnamed: R2.2, U1.8 (Rs)

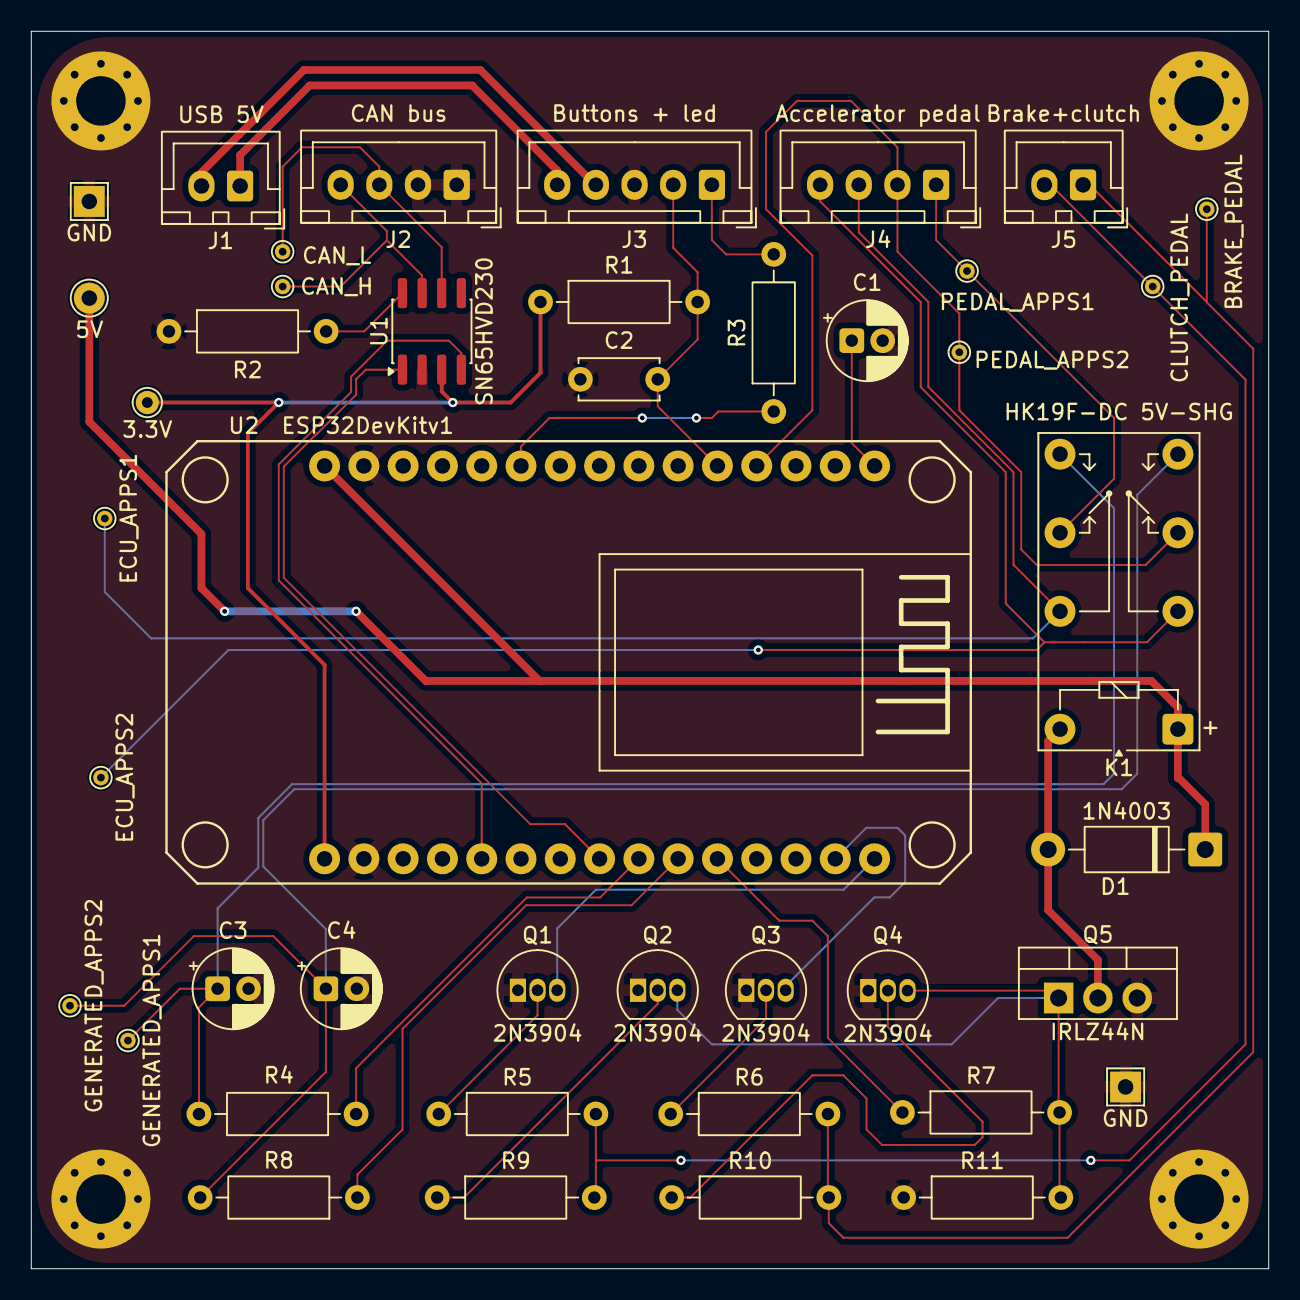
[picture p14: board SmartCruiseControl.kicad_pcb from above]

Board: 2 copper layers, 80.0 x 80.0 mm, 47 parts (0 on the bottom side), 33 nets.

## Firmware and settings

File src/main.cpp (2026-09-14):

#include <Arduino.h>
#include "error_codes.h"
#include "can_reader.h"
#include "elm327.h"
#include "indicator_led.h"
#include "throttle.h"
#include "brake_clutch.h"
#include "cruise_control.h"
#include "debug.h"

#define configCHECK_FOR_STACK_OVERFLOW 2

// Stack overflow callback
void vApplicationStackOverflowHook(TaskHandle_t xTask, char *pcTaskName) {
    printf("ERROR: Stack overflow in task %s\n", pcTaskName);

    // Disable interrupts
    taskDISABLE_INTERRUPTS();

    // Turn off throttle overriding
    Throttle::enableOverride(false);

    // Restart ESP32
    esp_restart();
}

static CanReader canReader;                  // Shared CAN reader instance
static Elm327 elm327(canReader);             // ELM327 emulator tied to CAN reader

// Main application task that runs the cruise control loop periodically
void mainTask(void* args) {
    VehicleState vehicleState;
    CruiseControl cruiseControl;

    const TickType_t period = pdMS_TO_TICKS(BUTTONS_QUERY_PERIOD_MS);
    TickType_t lastWakeTime = xTaskGetTickCount();

    uint8_t pidUpdateInterval = MAIN_LOOP_PERIOD_MS / BUTTONS_QUERY_PERIOD_MS;
    uint8_t counter = 0;

    while(true) {
        CCButton pressedButton = Buttons::getPressedCCButton();

        if(++counter >= pidUpdateInterval) {
            counter = 0;
            canReader.readState(vehicleState);                  // Read the latest vehicle state from CAN
            cruiseControl.loop(vehicleState, pressedButton);    // Run cruise control logic
        }

        vTaskDelayUntil(&lastWakeTime, period); // Sleep until next loop period
    }
}

// Test buttons and pedals
void testButtonsAndPedals() {
    VehicleState vehicleState;

    while(1) {
        bool turnOnLed = false;

        // Check pressed button
        Button button = Buttons::getPressedButton();
        switch(button) {
            case Button::BUTTON_REJECT_CALL:
                Serial.println("Button pressed: BUTTON_REJECT_CALL");
                turnOnLed = true;
                break;
            case Button::BUTTON_MUTE:
                Serial.println("Button pressed: BUTTON_MUTE");
                turnOnLed = true;
                break;
            case Button::BUTTON_ANSWER_CALL:
                Serial.println("Button pressed: BUTTON_ANSWER_CALL");
                turnOnLed = true;
                break;
            case Button::BUTTON_NEXT_TRACK:
                Serial.println("Button pressed: BUTTON_NEXT_TRACK");
                turnOnLed = true;
                break;
            case Button::BUTTON_PREVIOUS_TRACK:
                Serial.println("Button pressed: BUTTON_PREVIOUS_TRACK");
                turnOnLed = true;
                break;
            case Button::BUTTON_VOLUME_DOWN:
                Serial.println("Button pressed: BUTTON_VOLUME_DOWN");
                turnOnLed = true;
                break;
            case Button::BUTTON_VOLUME_UP:
                Serial.println("Button pressed: BUTTON_VOLUME_UP");
                turnOnLed = true;
                break;
        }

        // Check brake pedal
        if(BrakeClutch::isBrakePressed()) {
            Serial.println("Pedal pressed: BRAKE");
            turnOnLed = true;
        }

        // Check clutch pedal
        if(BrakeClutch::isClutchPressed()) {
            Serial.println("Pedal pressed: CLUTCH");
            turnOnLed = true;
        }

        // Read vehicle state
        canReader.readState(vehicleState);

        // Check parking brake
        if(vehicleState.parkingBrake) {
            Serial.println("Lever pressed: PARKING_BRAKE");
            turnOnLed = true;
        }

        // Check reverse light
        if(vehicleState.reverseLight) {
            Serial.println("Light activated: REVERSE_LIGHT");
            turnOnLed = true;
        }

        if(turnOnLed) {
            IndicatorLed::setState(SystemState::STATE_ACTIVE);
        } else {
            IndicatorLed::setState(SystemState::STATE_OFF);
        }

        delay(MAIN_LOOP_PERIOD_MS);
    }
}

// Fatal error handler: blinks an error code indefinitely using the indicator LED
void fatalErrorLoop(uint8_t code) {
    while(true) {
        for(uint8_t i=0; i<code; i++) {
            IndicatorLed::setState(SystemState::STATE_ACTIVE);
            delay(200);
            IndicatorLed::setState(SystemState::STATE_OFF);
            delay(200);
        }
        delay(1000); // Wait before repeating the error code
    }
}

// Arduino setup() initializes hardware and starts application tasks
void setup() {
    // Initialize status LED
    if(!IndicatorLed::init()) {
        fatalErrorLoop(ERROR_LED_INIT);
    }

    IndicatorLed::setState(SystemState::STATE_ACTIVE);

    // Initialize throttle outputs and inputs
    if(!Throttle::init()) {
        fatalErrorLoop(ERROR_THROTTLE_INIT);
    }

    // Initialize brake and clutch pins
    BrakeClutch::init();
    
    // Start CAN bus reception and processing
    if(!canReader.init()) {
        fatalErrorLoop(ERROR_CAN_READER_INIT);
    }

    // Wait a second for a button to be pressed to enter debug mode
    Debug::setEnabled(false);
    uint32_t buttonDebugTime = 0;
    while(buttonDebugTime < 1000) {
        Button button = Buttons::getPressedButton();
        if(button == Button::BUTTON_NONE) {
            delay(BUTTONS_QUERY_PERIOD_MS);
            buttonDebugTime += BUTTONS_QUERY_PERIOD_MS;
        } else {
            if(button == Button::BUTTON_MUTE) {
                // Enable button and pedals testing mode
                Debug::setEnabled(true);
                Serial.begin(SERIAL_DEBUG_BAUDRATE);
                Debug::println("Buttons debug mode is enabled");

                // Fade indicator LED for 4 seconds
                for(uint32_t time = 0; time < 4000; time += MAIN_LOOP_PERIOD_MS) {
                    IndicatorLed::setState(SystemState::STATE_OVERRIDE);
                    delay(MAIN_LOOP_PERIOD_MS);
                }

                IndicatorLed::setState(SystemState::STATE_OFF);
                testButtonsAndPedals();
            } else {
                // Enable debug mode
                Debug::setEnabled(true);
                Serial.begin(SERIAL_DEBUG_BAUDRATE);
                Debug::println("Debug mode is enabled");
    
                // Fade indicator LED for 2 seconds
                for(uint32_t time = 0; time < 2000; time += MAIN_LOOP_PERIOD_MS) {
                    IndicatorLed::setState(SystemState::STATE_OVERRIDE);
                    delay(MAIN_LOOP_PERIOD_MS);
                }
                break;
            }
        }
    }

    // Start ELM327 serial task if debug mode is not enabled
    if(!Debug::isEnabled()) {
        Serial.begin(SERIAL_ELM327_BAUDRATE);
        elm327.init();
    }

    IndicatorLed::setState(SystemState::STATE_OFF);

    xTaskCreatePinnedToCore(mainTask, "MainTask", 10000, nullptr, MAIN_TASK_PRIORITY, nullptr, APP_CORE_ID);
}

// Arduino loop() is idle because the app uses FreeRTOS tasks
void loop() {
    vTaskDelay(portMAX_DELAY);
}

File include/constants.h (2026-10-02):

#pragma once

#include <Arduino.h>

/* Main core and task constants */
#define PRO_CORE_ID 0                // ESP32 core used for CAN tasks
#define APP_CORE_ID 1                // ESP32 core used for application tasks

#define CAN_RX_TASK_PRIORITY 5       // Priority for CAN receive task
#define CAN_PROCESSING_TASK_PRIORITY 4 // Priority for CAN decoding task
#define ELM327_TASK_PRIORITY 1       // Priority for ELM327 serial task
#define MAIN_TASK_PRIORITY 2         // Priority for main cruise control loop task

#define MAIN_LOOP_PERIOD_MS 50        // Main control loop period in milliseconds

/* Cruise control limits and thresholds */
#define MAX_TARGET_SPEED_DIFF 25     // Maximum resume speed difference in km/h
#define MIN_SPEED_KMH 25             // Minimum allowed cruise speed
#define MAX_SPEED_KMH 135            // Maximum allowed cruise speed

#define MIN_CAR_SPEED_KMH (MIN_SPEED_KMH-5)  // Minimum allowed car speed
#define MAX_CAR_SPEED_KMH (MAX_SPEED_KMH+5)  // Maximum allowed car speed
#define MIN_RPM 1200                 // Minimum engine RPM for cruise control
#define MAX_RPM 3500                 // Maximum engine RPM for cruise control

#define THROTTLE_PEDAL_THRESHOLD_ENABLE 20   // Pedal percent threshold to bypass throttle override
#define THROTTLE_PEDAL_THRESHOLD_DISABLE 10  // Pedal percent threshold to re-enable throttle override

#define SPEED_TIMEOUT_MS 3000         // Maximum age of speed data before invalidation
#define RPM_TIMEOUT_MS 3000           // Maximum age of RPM data before invalidation

#define BRAKE_PEDAL_THRESHOLD 15      // Threshold to detect brake pedal in case hardware detection fails

/* PIDController constants */
#define PID_KP 0.25f                  // Proportional gain
#define PID_KI 0.02f                  // Integral gain
#define PID_KD 0.00f                  // Derivative gain
#define THROTTLE_RATE_UP_PER_SEC 0.60f   // Maximum throttle increase per second (60 % by default)
#define THROTTLE_RATE_DOWN_PER_SEC 0.80f // Maximum throttle decrease per second (80 % by default)
#define THROTTLE_MAX_DELTA_UP (THROTTLE_RATE_UP_PER_SEC * (MAIN_LOOP_PERIOD_MS / 1000.0f))
#define THROTTLE_MAX_DELTA_DOWN (THROTTLE_RATE_DOWN_PER_SEC * (MAIN_LOOP_PERIOD_MS / 1000.0f))

#define DERIVATIVE_ALPHA 0.9f           // Alpha value to smooth derivative
#define MAX_INTEGRAL_CONTRIBUTION 0.2f  // Max integral contribution to PID (20 % by default)
#define ANTI_WINDUP_GAIN 0.5f           // Anti windup gain
#define ERROR_DEADZONE 0.1f             // Dead zone for error values

/* Indicator LED constants */
#define INDICATOR_LED_PIN GPIO_NUM_27           // Status LED pin for cruise control state
#define INDICATOR_LED_PWM_CHANNEL 0             // PWM channel for indicator LED
#define INDICATOR_LED_BUILTIN_PIN GPIO_NUM_2    // Same as status LED but using internal LED
#define INDICATOR_LED_BUILTIN_PWM_CHANNEL 1     // PWM channel for builtin indicator LED
#define INDICATOR_LED_PWM_FREQ_HZ 1000          // PWM frequency for indicator LED
#define INDICATOR_LED_PWM_RESOLUTION_BITS 8     // PWM resolution bits for indicator LED
#define INDICATOR_LED_PWM_RESOLUTION (1<<INDICATOR_LED_PWM_RESOLUTION_BITS)
#define INDICATOR_LED_PWM_MAX (INDICATOR_LED_PWM_RESOLUTION-1)

/* Throttle output and input constants */
#define THROTTLE_APPS1_PIN GPIO_NUM_18            // PWM output for simulated APP sensor 1
#define THROTTLE_APPS2_PIN GPIO_NUM_19            // PWM output for simulated APP sensor 2
#define THROTTLE_APPS1_PWM_CHANNEL 2              // PWM channel for APP1 output
#define THROTTLE_APPS2_PWM_CHANNEL 3              // PWM channel for APP2 output
#define THROTTLE_PWM_FREQ_HZ 19000                // PWM frequency for throttle outputs
#define THROTTLE_PWM_RESOLUTION_BITS 12           // PWM resolution bits for throttle outputs
#define THROTTLE_PWM_RESOLUTION (1<<THROTTLE_PWM_RESOLUTION_BITS)
#define THROTTLE_PWM_MAX (THROTTLE_PWM_RESOLUTION-1)

#define CHECK_RELAY_MOSFET                     // Check if relay mosfet is actually enabled using a dedicated pin
#define CHECK_RELAY_MOSFET_PIN GPIO_NUM_25     // Pin connected to relay mosfet gate

#define THROTTLE_APPS2_PEDAL_PIN GPIO_NUM_34      // Analog input from actual accelerator pedal

#define THROTTLE_RELAY_PIN GPIO_NUM_21            // Relay control pin for throttle override

/* Brake and clutch constants */
#define BRAKE_PIN GPIO_NUM_22                     // Brake pedal pin      
#define CLUTCH_PIN GPIO_NUM_23                    // Clutch pedal pin

/* Buttons */
#define BUTTONS_PIN GPIO_NUM_35                   // Analog pin for button matrix readout
#define BUTTONS_MIN_CONSECUTIVE_READINGS 3        // Amount of consecutive readings to make sure a button has truly be pressed
#define BUTTONS_QUERY_PERIOD_MS 10                // Buttons query period in milliseconds.
                                                  // BUTTONS_QUERY_PERIOD_MS < MAIN_LOOP_PERIOD_MS and MAIN_LOOP_PERIOD_MS % BUTTONS_QUERY_PERIOD_MS == 0
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

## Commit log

2026-06-16 Added indicator led module
2026-06-16 Added throttle module
2026-06-16 Added brake_clutch module
2026-06-16 Added buttons module
2026-06-17 Replaced enum by enum class
    [main.cpp]
2026-06-17 Updated ADC module
2026-06-17 Updated buttons module
2026-06-17 Added constrain to throttle and brake intensity values
2026-06-17 Fixed bugs in elm327.cpp
    - Now responses are sent correctly
    - Now pid is validated to be HEX using end pointer parameter of strtol()
2026-06-18 Removed bracke_clutch module and added relay detection logic to throttle module
2026-06-18 Added ESP32 pinout image
2026-06-18 Added CAN bus reverse engineering.md
2026-06-18 Added throttle pedal documentation
2026-06-18 Added brake and clutch pedal switches documentation
2026-06-19 Added error check on init
    [main.cpp]
2026-06-22 Readded brake_clutch module
2026-06-23 Modified throttle, brake and clutch pins
2026-06-23 Updated brake-clutch example
2026-06-23 Fixed bug when responding to extended OBDII frames
2026-06-24 Added kicad project
    [SmartCruiseControl.kicad_pcb, SmartCruiseControl.kicad_sch]
2026-06-24 Added kicad library as submodule
2026-06-24 Added kicad preview files
2026-06-25 Fixed incorrect values in ELM327 module
    Rpm and voltage were incorrect and speed was always 0
2026-06-25 Updated fuel_range_estimator and added new extra PID 0x22000B for the used fuel liters value
2026-07-25 Modified buttons ADC range
2026-07-28 Improved pid_controller module and fixed critical bug
    PID output is in the range 0.0 - 1.0, so it's required to multiply it by 100.0
    [constants.h]
2026-07-29 Improved buttons module
2026-07-29 Added builtin LED as indicator LED too
2026-07-29 Changed led mode from half brightness to fading if override mode is active
2026-07-29 Removed Serial2 option + Turn on and off indicator LED when ESP32 starts
2026-07-30 Now speed can be increased and decreased if you keep pressing the corresponding button
2026-07-30 Moved buttons constants to correct file section
    [constants.h]
2026-07-31 Updated button calibration example code
2026-07-31 Now throttle pedal is read using ADC::readFiltered function to avoid spurious data values
2026-07-31 Now PID controller debug data is shown every 250 ms instead of every 50 ms
2026-07-31 Improved pid_controller
    kp, ki, kd, throttle rate and derivative_alpha have been adjusted and now pid_controller starts with current throttle rather than starting from 0
2026-08-07 Updated board to v1.1
    [SmartCruiseControl.kicad_pcb, SmartCruiseControl.kicad_sch]
2026-08-10 Added ESP32 3D model
    [DEVKIT_V1_ESP32-WROOM-32.step, SmartCruiseControl.kicad_pcb]
2026-08-11 Updated board version to v1.1.1
    Increased hole size from M2 to M3
    [SmartCruiseControl.kicad_pcb, SmartCruiseControl.kicad_sch]
2026-09-09 Changed status LED pin from 25 to 27
2026-09-13 Updated constants to prevent PID oscillations (See description) Kp has been changed from 0.45 to 0.25 Ki has been changed from 0.05 to 0.02 Kd has been changed from 0.20 to 0.00 Throttle rate up per 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
    [constants.h]
2026-09-13 Updated BOM link to a previewable format
2026-09-14 Now if SET button is pressed while pressing throttle pedal, target speed will be set to current speed
2026-09-14 Now cruise control can't be enabled if parking brake or reverse light are active
2026-09-14 Added buttons and pedals testing mode if MUTE button is pressed when ESP32 is turned ON
2026-10-01 Added threshold to detect brake pedal over CAN bus in case hardware detection fails
    [constants.h]
2026-10-01 Added option to check if mosfet relay is actually enabled
2026-10-02 Changed relay mofset pin from 15 to 25 because GPIO 15 is a strapping pin and it has HIGH value during ESP32 boot
2026-10-21 Added time value when printing debug data
2026-10-25 Now debug mode can be entered by pressing MUTE button anytime
    If that button is pressed during initilization, button and pedals testing mode will be enabled instead
2026-10-25 Fixed incorrect pedal debug message
    Brake pedal was being shown in debug info when clutch pedal was pressed (and brake pedal was not pressed)
